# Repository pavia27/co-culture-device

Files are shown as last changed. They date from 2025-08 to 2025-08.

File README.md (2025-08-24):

## Fabrication of modified BioMe microplate

Microplate components were fabricated using materials detailed in Table 1. The body segments were produced via a multi-step casting process. First, master parts were 3D printed (MES-MP-3434_BioMe2_Body_Segment_Rev2_Inner.STL and MES-MP-3434_BioMe2_Body_Segment_Rev2_Outer.STL) to create a high-fidelity negative mold from PlatSil Gel-25 Silicone Rubber. This mold was cured under 25 psi of positive pressure to eliminate voids. The cured mold was then filled with EasyFlo 60 Liquid Plastic again under 25 psi of positive pressure and allowed to solidify for 48 hours. The resulting solid plastic segments were drilled using a drill press, manually sanded (400-Grit) to create smooth sealing surfaces, and cleaned of residual manufacturing chemicals by agitation in deionized water on an orbital shaker for 48 hours.

The polycarbonate base plate was CNC-milled from polycarbonate sheets, while gaskets (MES-MP-3434_BioMe2_Body_Segment_Rev2.SLDPRT) were laser-cut from food grade silicone rubber sheets using a CAMFive CFL-CMA2416k 80-watt $CO_2$ laser cutter. The co-culture interface was prepared from 0.2 µm Nucleopore track-etched polycarbonate hydrophilic membranes. These membranes were cut into 8 mm circles with a leather punch, washed in 70% ethanol and air-dried before assembly.

Table 1: Materials used in modified BioMe microplate
| Material | Vendor/Catalogue# |
| --- | --- |
| Plastil Gel-25 | Polytek/GEL25U2 |
| EasyFlo 60 Liquid Plastic | Polytek/EZFLOU3.8 |
| 18-8 Stainless Steel Threaded Rod, 6" Long, 6-32 Tread Size | McMaster-Carr/95412A373 |
| 18-8 Stainless Steel Flange Nut, 6-32 Tread Size | McMaster-Carr/94758A102 |
| 18-8 Stainless Steel Narrow Hex Nut, 4-40 Thread Size | McMaster-Carr/90730A005 |
| 316 Stainless Steel Hex Drive Flat Head Screw, 82 Degree Countersink Angle, 4-40 Thread Size, 3/4" Long | McMaster-Carr/990585A206 |
| 1/32" Food-Grade High Temp Silicone Rubber Sheet (40A Medium Soft) | McMaster-Carr/86945K58 |
| Scratch- and UV-Resistant Polycarbonate 1/16” | McMaster-Carr/8707K161 |
| Nuclepore Hydrophilic Membrane, 0.2 µm pore size, 47 mm circle | Cytiva/10417012 |

## Assembly and Quality Control

The microplate was assembled according to the protocol established by Jo et al. [1], placing a silicone gasket between the polycarbonate base and the first body segment, as well as between each subsequent segment, to form a liquid-tight seal. Each plate consisted of four inner body segments (holes on both side faces) and two outer body segments (holes on one face side), which was done to increase structural integrity of devie. To ensure sterility and seal integrity: all screws and joints were kept intentionally loose before the entire apparatus was autoclaved using a gravity cycle (20-minute exposure, 20-minute dry time). Following sterilization, the plate was transferred to a disinfected biosafety cabinet where all joints were fully tightened to create the final, sterile seal. A final quality control check was performed on the assembled plate by adding 250 µL of sterile growth media to each well. The plate was incubated for 1 hour at room temperature and then a micropipette was used to measure any loss of volume.

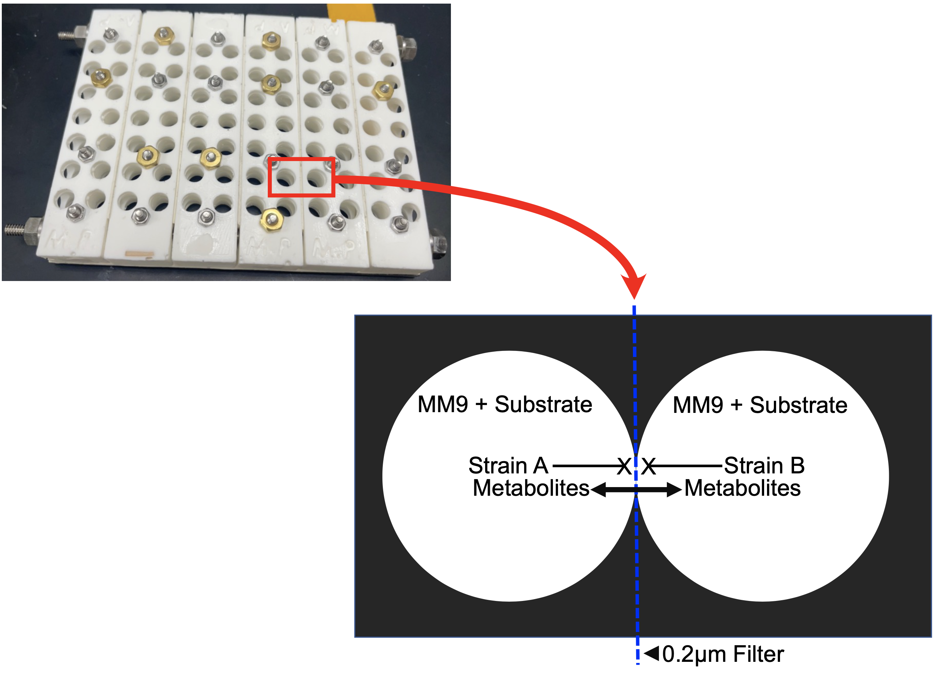
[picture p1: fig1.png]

The modified BioMe microplate from Jo et al. [1], depicted above, shows fully assembled unit. Each well is partitioned from its
counterpart by a 0.2µm pore-sized filter, that is securely positioned by a precision-cut
silicone sheet. The semi-permeable barrier, as indicated by the red arrow, is designed to
permit the passage of metabolites while preventing the translocation of microbes.

## Calibration and Validation

The fully assembled microplate was validated for both its optical properties and its biological application. First, the optical sensitivity and minimal detectable optical density ($OD_{600}$) were determined by generating a standard curve using McFarland standards ranging from 0.1 to 4 (Figure 1). Next, to ensure the polycarbonate material did not interfere with measurements, a comparative analysis of $OD_{600}$ readings was performed against a standard polystyrene 96-well plate. While no statistically significant difference was found overall (paired two-sample t-test, *p*=0.6656), it was noted that McFarland standards 1, 1.5, and 2 consistently produced marginally higher readings in the polycarbonate plate.

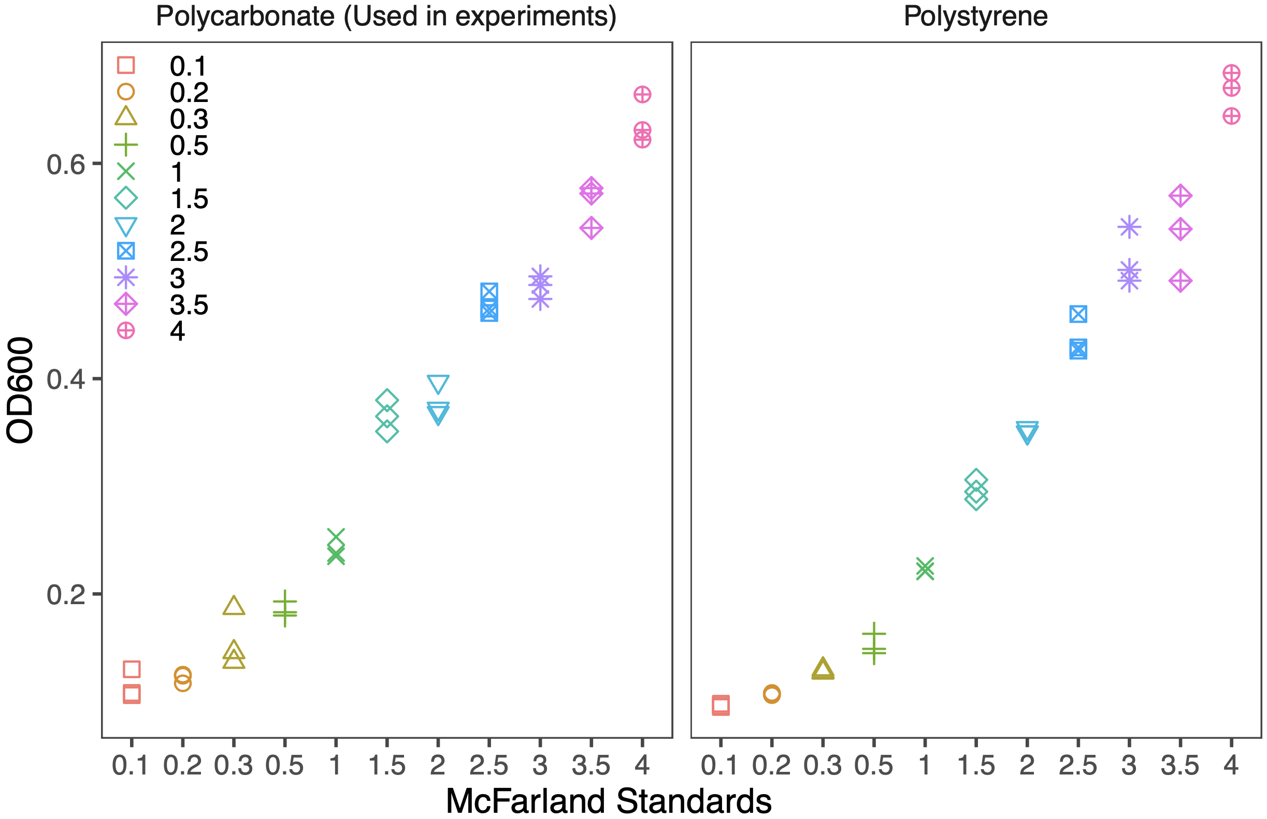
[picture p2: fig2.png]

Figure 1. Distribution of $OD_{600}$ across varying McFarland standards measured through polycarbonate and polystyrene material. Each point represents the $OD_{600}$ measurement for a given McFarland standard, color-coded, and shaped according to the standards.

The biological efficacy of the device was confirmed through a co-culture of *Lactobacillus plantarum* and *Acetobacter pasteurianus* in a chemically defined medium [2]. The resulting growth curves demonstrated the plate's ability to support microbial growth and detect known metabolic interactions, as evidenced by the enhanced growth of *A. pasteurianus* in co-culture (Figure 2).

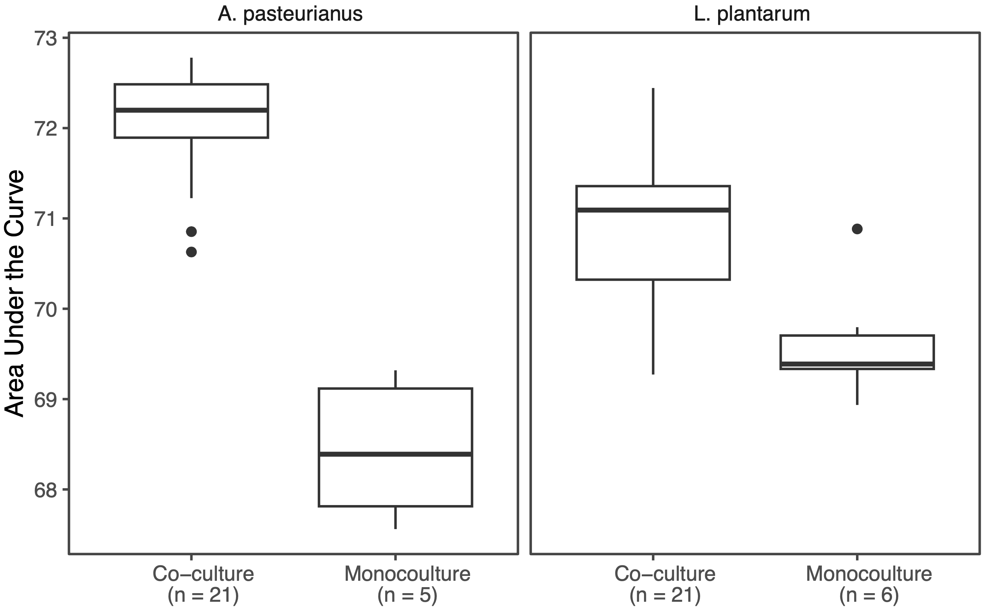
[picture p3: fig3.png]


Figure 2. Boxplots comparing the area under the curve for co-cultures and monocultures of A. pasteurianus and L. plantarum on the modified BioMe microplate. $OD_{600}$ normalization and area under the curve calculations were carried out in the same way as the PMFB strains. 

## Bibliography 
1.     Jo, C., et al., Construction and Modeling of a Coculture Microplate for Real-Time Measurement of Microbial Interactions. mSystems 8, (2023).
2.     Aumiller, K. et al., A chemically-defined growth medium to support Lactobacillus-Acetobacter sp. community analysis. PLoS One 18, 1–12 (2023).

## Citation
Pavia, MJ., Muse, C., Brownell, Z., Bean, HD., Cadillo-Quiroz, H. (2025) Substrate driven microbial interactions across geochemically distinct tropical peatlands *(in review)*

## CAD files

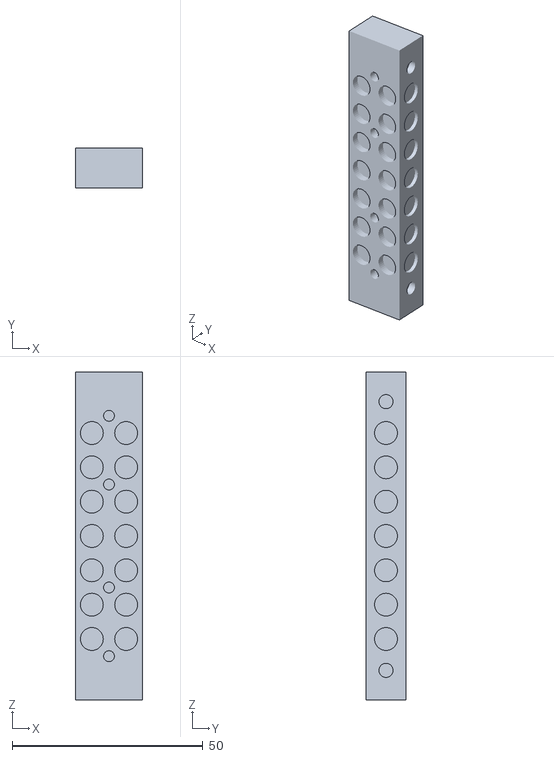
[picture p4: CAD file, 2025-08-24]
MES-MP-3434_BioMe2_Body_Segment_Rev2_Inner.STL
17.6 x 10.5 x 86.0

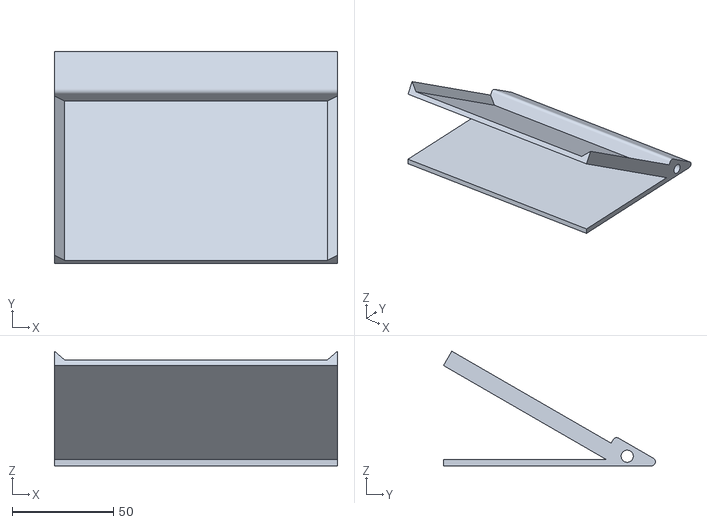
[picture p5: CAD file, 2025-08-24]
96well-locator-stand.stl
140.0 x 104.9 x 56.7

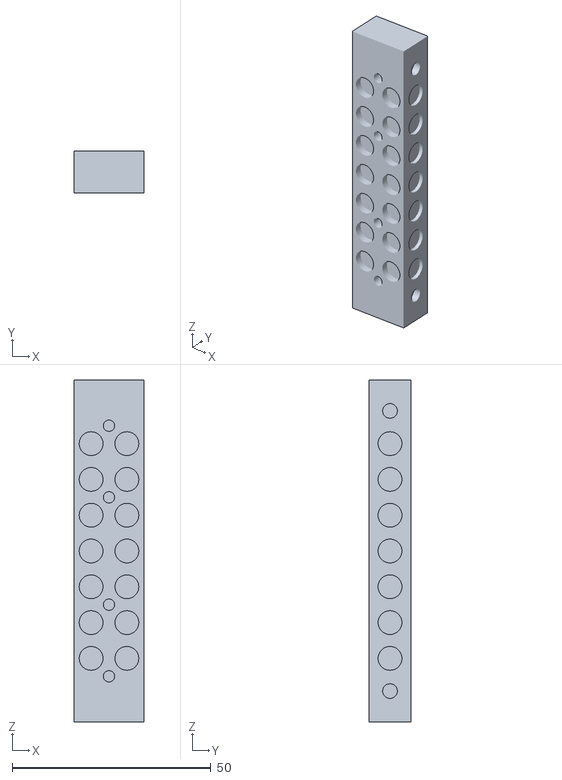
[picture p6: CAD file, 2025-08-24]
MES-MP-3434_BioMe2_Body_Segment_Rev2_Outer.STL
17.6 x 10.5 x 86.0

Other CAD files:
MES-MP-3434_BioMe2_Body_Segment_Rev2.SLDPRT
